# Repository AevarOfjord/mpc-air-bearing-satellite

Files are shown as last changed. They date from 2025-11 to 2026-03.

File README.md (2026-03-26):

# Satellite Thruster Control System





> **📌 Read-Only Reference Implementation**
>
> This repository is provided as a **complete reference implementation** for educational and research use. It is **not actively maintained** for external contributions.
>
> - ✅ **Download, fork, and modify** for your own research
> - ✅ **Open a GitHub issue** for bugs, documentation problems, or questions about the reference implementation
> - ❌ **Pull requests are not accepted** for this repository
> - ❌ **GitHub Discussions are not enabled**
> - 📧 **For urgent matters**: ofjord99@gmail.com

---

## What is This?

An **autonomous satellite control system** that uses **Model Predictive Control (MPC)** to navigate a satellite testbed on a 6×6 meter air-bearing table.

**In plain terms**: A small satellite floats frictionlessly on air bearings. It uses 8 compressed air thrusters and advanced control algorithms to move to targets and follow paths. Everything runs in software (simulation) or on real hardware.

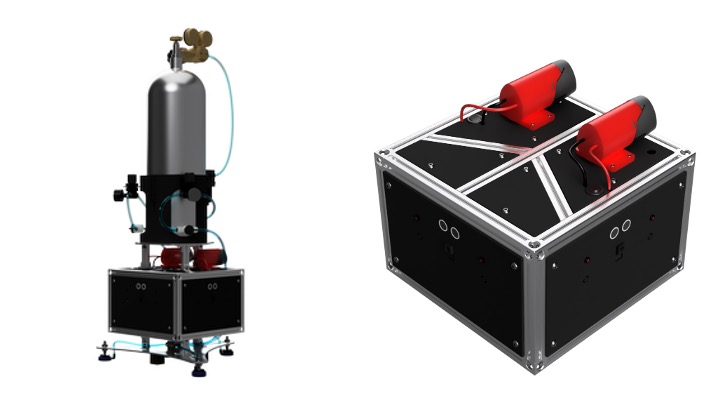
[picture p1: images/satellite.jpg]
Rendered Images of the Satellite and the Platform


---

## Quick Start

### 1. Install Python Dependencies
```bash
python3 -m pip install .
```

### 2. Get Gurobi License (Free for Academia)
- Visit: https://www.gurobi.com/academia/academic-program-and-licenses/
- Register with `.edu` email → download `gurobi.lic`
- Keep `gurobi.lic` local only. Placing it in the project root is supported and gitignored.

### 3. Run Simulation
```bash
satellite-sim
```
Follow the prompts to navigate to waypoints or follow shapes.

---

## What's Included

| What | What it Does | Command |
|---|---|---|
| **simulation.py** | Run MPC control on virtual satellite | `satellite-sim` or `python3 simulation.py` |
| **real.py** | Run MPC control on real hardware | `satellite-real` or `python3 real.py` |
| **mpc.py** | MPC solver & optimization logic | Imported by sim/real |
| **visualize.py** | Creates animations & performance plots (done automatically after each run, or manually) | `satellite-visualize` or `python3 visualize.py` |
| **comparison.py** | Compare sim vs real hardware results | `python3 comparison.py` |
| **testing_environment.py** | Manual control interface | `satellite-test` or `python3 testing_environment.py` |
| **config/** | All system parameters (physics, timing, MPC) | Import as needed |

---

## Documentation

### I'm taking over this project (handoff)
→ See [HANDOFF_GUIDE.md](HANDOFF_GUIDE.md) - Week 1 checklist, system health checks, maintenance schedule, known quirks

### I want to understand the system architecture
→ See [ARCHITECTURE.md](ARCHITECTURE.md) - Deep dive into control algorithms, physics model, module design

### I want to run hardware tests
→ See [HARDWARE_TEST_PROCEDURE.md](HARDWARE_TEST_PROCEDURE.md) - Safety checks, calibration, real-world testing

### I want to understand the mission types
→ See [MISSION_ARCHITECTURE.md](MISSION_ARCHITECTURE.md) - Waypoint navigation, shape following, DXF support

### I want to extend or modify the code
→ See [DEVELOPMENT_GUIDE.md](DEVELOPMENT_GUIDE.md) - Adding features, code style, testing your changes

### I want comprehensive simulation testing
→ See [SIMULATION_TESTING_GUIDE.md](SIMULATION_TESTING_GUIDE.md) - Simulation modes, parameter tuning, validation

### I want to understand data formats
→ See [CSV_FORMAT.md](CSV_FORMAT.md) - Data structure, analysis examples

### I want to write or understand tests
→ See [TESTING_GUIDE.md](TESTING_GUIDE.md) - Test structure, running tests, writing new tests

### I encountered a problem
→ See [TROUBLESHOOTING.md](TROUBLESHOOTING.md) - Installation, runtime, hardware, and data issues

---

## Key Features

- **Full Simulation**: Physics-based satellite dynamics with realistic thruster behavior
- **Real Hardware Control**: MPC on actual 6×6m air-bearing testbed
- **8 Thruster Control**: Individual calibration for each thruster
- **Multiple Mission Types**: Waypoint navigation, shape following (circle, rectangle, triangle, hexagon, custom DXF)
- **Visualization**: Animated results + performance plots
- **Comprehensive Tests**: 300+ unit and integration tests
- **Research Foundation**: Modular, extensible architecture for new control strategies

---

## Installation

### Prerequisites
- **Python 3.9, 3.10, 3.11, or 3.12** (3.13+ not supported yet)
- Check your version: `python3 --version`

### Steps
```bash
# 1. Install the package and runtime dependencies
python3 -m pip install .

# 2. Get free academic Gurobi license
# - Visit: https://www.gurobi.com/academia/academic-program-and-licenses/
# - Register with .edu email → download gurobi.lic
# - Keep gurobi.lic local only
# - Project root is supported and gitignored

# 3. Install FFmpeg
# macOS: brew install ffmpeg
# Linux: sudo apt install ffmpeg
# Windows: https://ffmpeg.org/download.html

# 4. Verify everything works
python3 -c "import gurobipy; print('Gurobi OK')"
python3 simulation.py
```

---

## Common Tasks

| Task | Command | Output |
|---|---|---|
| Run simulation | `python3 simulation.py` | CSV data + MP4 animation + plots |
| Run hardware control | `python3 real.py` | Live hardware control + CSV data + MP4 animation + plots + Live video |
| Generate visualizations | `python3 visualize.py` | Manually creates MP4 animation + PNG plots from selected CSV data file|
| Compare sim vs real | `python3 comparison.py` | Side-by-side analysis |
| Manual control in simulated environment| `python3 testing_environment.py` | Live interactive interface to test simulation environment |
| Run tests | `pytest` | Test results + coverage |

---

## Troubleshooting

**Python 3.13+ not supported?**
→ Use Python 3.9-3.12 instead. Install from https://www.python.org/downloads/

**"No module named gurobipy"?**
→ Install Gurobi (free academic license) and keep `gurobi.lic` local only. The project root is supported and gitignored.

**Serial port errors?**
→ Update `SERIAL_PORT` in config/constants.py. Check Device Manager (Windows) or `ls /dev/tty.*` (Mac/Linux)

**MPC solver too slow?**
→ Reduce `MPC_PREDICTION_HORIZON` in config/mpc_params.py

**FFmpeg not found?**
→ Install FFmpeg or update `FFMPEG_PATH` in config

For more troubleshooting, see [TROUBLESHOOTING.md](TROUBLESHOOTING.md)

---

## About This Project

Master's thesis project from University of Kentucky Mechanical Engineering. The system demonstrates Model Predictive Control for autonomous satellite navigation on a 6×6m air-bearing testbed.

**Why it exists**: Research platform for studying MPC-based attitude and position control with real hardware validation.

**Who should use it**: Researchers, students, and educators interested in control systems and autonomous satellite operations.

### Vision for Others

This project was designed with **extensibility and replicability** in mind. If you're interested in MPC research or small satellite testing:

- **Download and adapt**: Fork this repo and customize for your hardware
- **Reference implementation**: Use as a starting point so you don't have to build from scratch
- **MPC controller**: The core `mpc.py` works with any air-bearing testbed (adjust physics parameters)
- **Simulation**: Validate algorithms in software before hardware investment

**Note**: I want to maintain this as a reference implementation. You're welcome to fork and adapt it for your own research, but modifications stay on your own copy. This ensures the canonical version remains stable for others.

---

## Contributing

This is a personal research project released for educational and reference use. I do **not accept pull requests**, but you can fork and modify it for your own work.

### If you find issues:

- **Report bugs or documentation issues**: Open an issue at https://github.com/AevarOfjord/mpc-air-bearing-satellite/issues
- **Hardware concerns**: Use the same issue tracker and include setup details, logs, and reproduction steps
- **Questions about adapting the project**: Open an issue so the answer is visible to future users of the reference repo

### Want to modify the code?

**Fork and adapt for your research.** See [DEVELOPMENT_GUIDE.md](DEVELOPMENT_GUIDE.md) for setup and workflow details.

**Note**: This project is released as-is for educational and reference use. Bug fixes and improvements are made on a best-effort basis through the maintainer's own branch, not through incoming pull requests.

---

## Credits and Acknowledgments

**Author**: Aevar Amundinusarson Oefjoerd (Master's Thesis Project)

**Advisors**:
- Dr. Poonawala
- Dr. Seigler

**Institution**: University of Kentucky, Department of Mechanical Engineering

**Key Technologies**:
- **Gurobi Optimization**: Academic license for MPC solver
- **Python Scientific Stack**: NumPy, SciPy, Matplotlib
- **PyQt5**: User interface framework
- **OptiTrack Motive**: Motion capture system
- **FFmpeg**: Video generation

**Acknowledgments**:
- Dr. Poonawala, Dr. Seigler, UK Mechanical Engineering faculty and staff for facility access and support
- Open source community for excellent tools and libraries

---

## Support

**Repository**: https://github.com/AevarOfjord/mpc-air-bearing-satellite

**Issues**: https://github.com/AevarOfjord/mpc-air-bearing-satellite/issues

Need help? Check [TROUBLESHOOTING.md](TROUBLESHOOTING.md) or open an issue.

---

**Ready to get started?**
```bash
satellite-sim
```

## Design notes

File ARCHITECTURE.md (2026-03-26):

# Satellite Thruster Control System - Architecture Documentation

This document provides a complete file listing and description of the system architecture. For project overview and features, see [README.md](README.md).

---

## Directory Structure
```
mpc-air-bearing-satellite/
│
├── Main Entry Points (root level)
│   ├── simulation.py                 # Simulation environment launcher
│   ├── real.py                       # Real hardware control launcher
│   ├── visualize.py                  # Unified visualization & animation
│   ├── comparison.py                 # Compare simulation vs real results
│   └── testing_environment.py        # Interactive physics testing
│
├── Core Control & Physics
│   ├── mpc.py                        # Model Predictive Control optimizer
│   ├── model.py                      # Satellite physics model
│   ├── mission.py                    # Mission logic & waypoint handling
│   ├── mission_state_manager.py      # Track mission state
│   └── mission_report_generator.py   # Generate mission reports
│
├── Hardware & Communication
│   ├── satellite_hardware_interface.py   # Serial communication
│   ├── telemetry_client.py              # Motion capture data polling
│   └── camera_manager.py                # Multi-camera streaming
│
├── Navigation & Planning
│   ├── path_planning_manager.py     # Obstacle avoidance
│   └── navigation_utils.py          # Geometric utilities
│
├── Data & Logging
│   ├── data_logger.py               # CSV export
│   ├── extract_initial_velocities.py # Velocity extraction
│   └── real_data_simulated.py       # Data playback
│
├── UI & Visualization
│   ├── simulation_visualization.py   # Animation generation
│   ├── real_ui_components.py        # Real-time dashboard
│   ├── gui_components.py            # Shared GUI components
│   └── visualization_manager.py     # Visualization orchestration
│
├── Modes & Setup
│   ├── simulation_test_modes.py      # Simulation mode menu
│   ├── real_test_modes.py           # Hardware mode menu
│   ├── mode_setup_manager.py        # Unified setup logic
│   └── simulation_state_validator.py # State validation
│
├── Utilities & Infrastructure
│   ├── exceptions.py                # Custom exceptions
│   ├── logging_config.py            # Logging configuration
│   └── satellite_config.py          # Central config wrapper interface
│
├── Configuration System (config/)
│   ├── __init__.py                  # Package initialization
│   ├── physics.py                   # Physical parameters
│   ├── timing.py                    # Timing parameters
│   ├── mpc_params.py                # MPC tuning parameters
│   ├── camera.py                    # Camera configuration
│   ├── constants.py                 # System constants
│   ├── mission_state.py             # Mission state
│   └── obstacles.py                 # Obstacle definitions
│
├── Motion Capture Integration (Motive/)
│   ├── nat_net_client.py            # NatNet protocol client
│   ├── motive_data_server.py        # HTTP data server
│   ├── mocap_data.py                # Motion capture data structures
│   └── data_descriptions.py         # NatNet format definitions
│
├── Shape & DXF Processing (DXF/)
│   ├── __init__.py                  # Package initialization
│   ├── dxf_viewer.py                # DXF file viewer
│   ├── dxf_shape_maker.py           # DXF file creator
│   └── DXF_Files/                   # Pre-defined shape files
│       ├── Shape1.dxf
│       ├── Shape2.dxf
│       ├── Shape3.dxf
│       ├── Shape4.dxf
│       └── Shape5.dxf
│
├── Thruster Testing & Calibration (Thruster_Test/)
│   ├── thruster_test.py             # Sequential thruster verification
│   ├── thrust_calibration.py        # Thruster force calibration
│   ├── analyze_thruster_data.py     # Calibration data analysis
│   └── Thruster_Data/               # Calibration test results
│
├── Testing Infrastructure (tests/)
│   ├── __init__.py                  # Package initialization
│   ├── README.md                    # Testing documentation
│   ├── conftest.py                  # pytest configuration
│   ├── test_config.py               # Configuration tests
│   ├── test_mpc_controller.py       # MPC tests
│   ├── test_model.py                # Physics model tests
│   ├── test_mission_state_manager.py # Mission state tests
│   ├── test_path_planning_manager.py # Path planning tests
│   ├── test_navigation_utils.py     # Navigation utility tests
│   ├── test_data_logger.py          # Data logging tests
│   ├── test_camera_manager.py       # Camera manager tests
│   ├── test_simulation_state_validator.py # State validation tests
│   ├── test_integration_basic.py    # Basic integration tests
│   └── test_integration_missions.py # Mission integration tests
│
├── Data Output (Data/)
│   ├── Simulation/                  # Simulation results
│   ├── Real_Test/                   # Hardware test results
│   └── Comparison/                  # Comparative analysis
│
├── Project Files
│   ├── README.md                    # Project overview & quick start
│   ├── ARCHITECTURE.md              # This file
│   ├── MISSION_ARCHITECTURE.md      # Mission system architecture
│   ├── HANDOFF_GUIDE.md             # Handoff documentation
│   ├── QUICK_START_CHECKLIST.md     # First week checklist
│   ├── HARDWARE_TEST_PROCEDURE.md   # Hardware testing guide
│   ├── THRUSTER_CALIBRATION.md      # Thruster calibration guide
│   ├── DEVELOPMENT_GUIDE.md         # Development guidelines
│   ├── TESTING_GUIDE.md             # Testing documentation
│   ├── SIMULATION_TESTING_GUIDE.md  # Simulation testing guide
│   ├── TROUBLESHOOTING.md           # Troubleshooting guide
│   ├── CSV_FORMAT.md                # CSV data format documentation
│   ├── CODE_OF_CONDUCT.md           # Code of conduct
│   ├── SECURITY.md                  # Security policy
│   ├── LESSONS_LEARNED.md           # Development lessons learned
│   ├── requirements.txt             # Python dependencies
│   ├── pyproject.toml               # Project metadata
│   ├── .gitignore                   # Git ignore rules for local artifacts and secrets
│   └── LICENSE                      # License
│
├── Images (images/)                 # Project images and diagrams
│
└── Virtual Environment (venv/)      # Python virtual environment

```

---

## Complete File Listing

### Root Level - Main Entry Points

| File | Purpose |
|---|---|
| [simulation.py](simulation.py) | Main entry point for physics-based simulation of satellite control with MPC optimization. |
| [real.py](real.py) | Main entry point for real hardware control system that interfaces with microcontroller and motion capture. |
| [visualize.py](visualize.py) | Unified visualization system that generates MP4 animations and performance plots from CSV data. |
| [comparison.py](comparison.py) | Compares simulation results against real hardware test results side-by-side. |
| [testing_environment.py](testing_environment.py) | Interactive testing interface for virtual satellite simulation and physics validation. |

### Core Control & Physics

| File | Purpose |
|---|---|
| [mpc.py](mpc.py) | Model Predictive Control optimizer using Gurobi to generate thruster commands. |
| [model.py](model.py) | Static 2D visualization of the satellite layout (thruster positions, COM, air bearings). |
| [mission.py](mission.py) | Unified mission module supporting waypoint navigation and shape-following behaviors. |
| [mission_state_manager.py](mission_state_manager.py) | Tracks mission state, waypoint progress, and determines when targets are reached. |
| [mission_report_generator.py](mission_report_generator.py) | Generates text summaries and performance analysis after missions complete. |

### Hardware & Communication

| File | Purpose |
|---|---|
| [satellite_hardware_interface.py](satellite_hardware_interface.py) | Abstracts serial communication with microcontroller for thruster commands. |
| [telemetry_client.py](telemetry_client.py) | HTTP client that polls motion capture data from Motive data server. |
| [camera_manager.py](camera_manager.py) | Manages multi-camera streaming and recording from ESP32-CAM modules. |

### Navigation & Planning

| File | Purpose |
|---|---|
| [path_planning_manager.py](path_planning_manager.py) | Generates safe paths around obstacles using intermediate waypoint insertion. |
| [navigation_utils.py](navigation_utils.py) | Geometric utilities for distance calculations, angle conversions, and path validation. |

### Data & Logging

| File | Purpose |
|---|---|
| [data_logger.py](data_logger.py) | Exports mission state and control data to CSV format for analysis. |
| [extract_initial_velocities.py](extract_initial_velocities.py) | Utility to extract initial velocity estimates from CSV data for controller initialization. |
| [real_data_simulated.py](real_data_simulated.py) | Playback mode that replays real hardware data through simulation.|

### UI & Visualization

| File | Purpose |
|---|---|
| [simulation_visualization.py](simulation_visualization.py) | Generates real-time animation of satellite trajectory with thrust vectors during simulation. |
| [real_ui_components.py](real_ui_components.py) | PyQt5 components for real-time monitoring dashboard during hardware missions. |
| [gui_components.py](gui_components.py) | Shared GUI components and widgets used across both simulation and hardware modes. |
| [visualization_manager.py](visualization_manager.py) | Orchestrates animation generation, plot creation, and media export. |

### Configuration System

| File | Purpose |
|---|---|
| [config/__init__.py](config/__init__.py) | Configuration package exports all dataclass modules. |
| [config/physics.py](config/physics.py) | Physical parameters: satellite mass, inertia, thruster positions, forces, drag coefficients. |
| [config/timing.py](config/timing.py) | Timing parameters: simulation timestep, control rate, stabilization delays. |
| [config/mpc_params.py](config/mpc_params.py) | MPC tuning: prediction horizon, control horizon, cost weights, constraints. |
| [config/camera.py](config/camera.py) | Camera configuration: ESP32-CAM URLs, recording settings, frame rates. |
| [config/constants.py](config/constants.py) | System constants: serial ports, network parameters, data paths, UI dimensions. |
| [config/mission_state.py](config/mission_state.py) | Runtime mission state tracking: waypoints, targets, phase information. |
| [config/obstacles.py](config/obstacles.py) | Obstacle definitions: circular obstacles with safety radii for path planning. |

### Modes & Setup

| File | Purpose |
|---|---|
| [simulation_test_modes.py](simulation_test_modes.py) | Interactive menu for selecting simulation scenarios (waypoint, shapes, DXF). |
| [real_test_modes.py](real_test_modes.py) | Interactive menu for real hardware missions with manual parameter input. |
| [mode_setup_manager.py](mode_setup_manager.py) | Unified setup logic for initializing simulation or hardware modes. |
| [simulation_state_validator.py](simulation_state_validator.py) | Validation checks for simulation state consistency and physics constraints. |

### Utilities & Infrastructure

| File | Purpose |
|---|---|
| [exceptions.py](exceptions.py) | Custom exception classes for mission, hardware, and control errors. |
| [logging_config.py](logging_config.py) | Centralized logging configuration with file and console handlers. |
| [satellite_config.py](satellite_config.py) | Unified wrapper interface for accessing configuration modules with thruster calibration support. |

### Motion Capture Integration (Motive)

| File | Purpose |
|---|---|
| [Motive/nat_net_client.py](Motive/nat_net_client.py) | OptiTrack NatNet protocol client for receiving UDP motion capture packets. |
| [Motive/motive_data_server.py](Motive/motive_data_server.py) | HTTP server exposing latest motion capture data as JSON endpoints. |
| [Motive/mocap_data.py](Motive/mocap_data.py) | Data structures for rigid body tracking, skeletons, markers, and force plates. |
| [Motive/data_descriptions.py](Motive/data_descriptions.py) | NatNet packet format definitions and unpacking utilities. |

### Shape & DXF Processing

| File | Purpose |
|---|---|
| [DXF/dxf_viewer.py](DXF/dxf_viewer.py) | Loads and visualizes DXF shape files with customizable offset and smoothing. |
| [DXF/dxf_shape_maker.py](DXF/dxf_shape_maker.py) | Creates DXF shape files for defining custom mission paths and obstacles. |
| [DXF/__init__.py](DXF/__init__.py) | DXF module package initialization. |

### Thruster Testing & Calibration

| File | Purpose |
|---|---|
| [Thruster_Test/thruster_test.py](Thruster_Test/thruster_test.py) | Quick sequential verification that fires each of 8 thrusters for 1 second. |
| [Thruster_Test/thrust_calibration.py](Thruster_Test/thrust_calibration.py) | Measures actual thruster forces and updates physics configuration with calibrated values. |
| [Thruster_Test/analyze_thruster_data.py](Thruster_Test/analyze_thruster_data.py) | Analyzes thrust calibration data and generates performance statistics. |

### Testing Infrastructure

| File | Purpose |
|---|---|
| [tests/__init__.py](tests/__init__.py) | Test package initialization. |
| [tests/README.md](tests/README.md) | Testing documentation and guidelines. |
| [tests/conftest.py](tests/conftest.py) | pytest fixtures and configuration for unit and integration tests. |
| [tests/test_config.py](tests/test_config.py) | Tests for configuration system and parameter validation. |
| [tests/test_mpc_controller.py](tests/test_mpc_controller.py) | Tests for MPC optimization, constraint handling, and solver accuracy. |
| [tests/test_model.py](tests/test_model.py) | Tests for physics model linearization and state updates. |
| [tests/test_mission_state_manager.py](tests/test_mission_state_manager.py) | Tests for mission state tracking and waypoint detection. |
| [tests/test_path_planning_manager.py](tests/test_path_planning_manager.py) | Tests for obstacle avoidance and path validation. |
| [tests/test_navigation_utils.py](tests/test_navigation_utils.py) | Tests for geometric calculations and angle conversions. |
| [tests/test_data_logger.py](tests/test_data_logger.py) | Tests for CSV export and data format correctness. |
| [tests/test_camera_manager.py](tests/test_camera_manager.py) | Tests for camera streaming and recording functionality. |
| [tests/test_simulation_state_validator.py](tests/test_simulation_state_validator.py) | Tests for physics constraint validation. |
| [tests/test_integration_basic.py](tests/test_integration_basic.py) | Integration tests for basic mission execution. |
| [tests/test_integration_missions.py](tests/test_integration_missions.py) | Integration tests for complex multi-waypoint and shape-following missions. |

---

## Architecture Layers

The system is organized into logical layers:

1. **User/Test Input** – mission scripts (`mission.py`, the test-mode menus) collect targets, mission type, obstacles, etc.
2. **Entry Point** – either `simulation.py` or `real.py` boots up the runtime, wiring in mission config, MPC, logging, visualization, etc.
3. **Mission Logic** – `mission_state_manager.py` (plus `path_planning_manager.py` if obstacles exist) figures out the current waypoint/DXF segment the controller needs to track.
4. **MPC Optimization** – `mpc.py` linearizes around the current state, builds the MIQP, and solves for the next thruster sequence.
5. **Execution Layer** – the optimal command is applied either to the virtual satellite (`SatelliteThrusterTester` in the simulator) or over to the real hardware via `satellite_hardware_interface.py` + OptiTrack telemetry.
6. **Data & Visualization** – every step is logged (`data_logger.py`) and rendered (`visualize.py`) after the mission has completed/stopped.

```mermaid
graph TD
    U[User / Mission Input<br/><code>mission.py</code>, test modes] --> A[Workflow Entry<br/><code>simulation.py</code> or <code>real.py</code>]
    A --> B[Mission Logic<br/><code>mission_state_manager.py</code><br/>Path planning if needed]
    B --> C[MPC Optimization<br/><code>mpc.py</code><br/>Build/solve MIQP]
    C --> D[Execution Layer<br/>Simulation: <code>SatelliteThrusterTester</code><br/>Hardware: <code>satellite_hardware_interface.py</code> + OptiTrack]
    D --> E[Data & Visualization<br/><code>data_logger.py</code> · <code>visualize.py</code> · dashboards]
    G[[Configuration Layer<br/><code>config/*</code> dataclasses]] -. feeds all .-> U
    G -. feeds all .-> A
    G -. feeds all .-> B
    G -. feeds all .-> C
    G -. feeds all .-> D
    G -. feeds all .-> E

    style U fill:#fff5d9,stroke:#d97706,stroke-width:1.2px
    style A fill:#dbeafe,stroke:#1d4ed8,stroke-width:1.2px
    style B fill:#dcfce7,stroke:#15803d,stroke-width:1.2px
    style C fill:#fce7f3,stroke:#be185d,stroke-width:1.2px
    style D fill:#fef9c3,stroke:#ca8a04,stroke-width:1.2px
    style E fill:#ede9fe,stroke:#6d28d9,stroke-width:1.2px
    style G fill:#f5f5f5,stroke:#374151,stroke-width:1.2px,stroke-dasharray: 5 3
```

---

### **Key Architectural Differences**

| Aspect | Simulation Mode | Hardware Mode |
|---|---|---|
| **State Source** | Ground truth from `SatelliteThrusterTester` | OptiTrack telemetry via `telemetry_client.py` |
| **Satellite Dynamics** | 50 Hz integrator with valve delays, ramp-up/down, damping, and optional disturbances (`testing_environment.py`) | Physical air-bearing vehicle with solenoids and supply pressure dynamics |
| **Sensor Input** | Perfect pose plus OptiTrack-like noise injected by `SimulationStateValidator` when `USE_REALISTIC_PHYSICS=True` | Raw OptiTrack pose differentiated in `real.py:update_state_from_telemetry()` |
| **Thruster Execution** | Commands immediately update the simulated valves; the same delay/ramp profiles are emulated in software | Commands are serialized through `satellite_hardware_interface.py` to the microcontroller and actuate the real valves |
| **Telemetry Path** | Internal state arrays (no networking) | HTTP polling from `Motive/motive_data_server.py` with retry/backoff |
| **Control Output** | Applied directly to the physics loop | Sent to the hardware interface (serial/UDP/TCP) |

Both modes call `MissionStateManager.update_target_state()` immediately before every MPC solve; the only difference is whether the current state comes from OptiTrack or the simulator and whether the vehicle response is physical hardware or the `SatelliteThrusterTester`.

---

### **Common Elements**

Both simulation and hardware modes use the same components for core functionality:

1. **MPC Controller** (`mpc.py`) - Identical optimization engine for both
2. **Mission Logic** (`mission.py`) - Same waypoint/shape-following logic
3. **Data Logging** (`data_logger.py`) - Identical CSV recording format
4. **Path Planning** (`path_planning_manager.py`) - Shared
5. **Post-Processing** (`visualize.py`) - Same animation/plot generation

---

## Key Design Principles

- **Modularity:** Each file has a single, clear responsibility
- **Configuration-driven:** All parameters in `config/` dataclasses
- **Simulation/Hardware parity:** Same `mpc.py` and `mission.py` code used for both modes
- **Testing:** Comprehensive unit and integration tests for all core components
- **Documentation:** Each file has docstring describing its purpose

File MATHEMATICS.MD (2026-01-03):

# Mathematical Documentation

## Notation Conventions

| Notation | Meaning | Example |
| --- | --- | --- |
| **Bold lowercase** (𝐱, 𝐮, 𝐯) | Column vectors | 𝐱 = [x, y, θ]ᵀ |
| **Bold uppercase** (𝐀, 𝐁, 𝐑) | Matrices | 𝐀 ∈ ℝ⁶ˣ⁶ |
| Subscript k | Time step index | x_k (state at time k) |
| Superscript \* | Optimal value | u\* (optimal control) |
| Hat (x̂) | Estimated/predicted value | x̂\_{k+1} (predicted state) |
| Δ (delta prefix) | Deviation from nominal / discrete step | Δx = x - x₀, Δt = timestep |
| ‖·‖ | Euclidean norm | ‖𝐱‖ = √(x² + y²) |
| ‖·‖\_Q | Weighted norm | ‖𝐱‖²_Q = 𝐱ᵀQ𝐱 |
| ∈ | Element of set | u ∈ {0,1} |
| ℝ | Real numbers | x ∈ ℝ |
| 𝒪(·) | Big-O notation: "scales as" or "on the order of" | Error = 𝒪(Δt²) means error grows proportionally to Δt² |

**Frame Notation:**

- Subscript "world" or "w": world/inertial frame tied to the OptiTrack reference
- Subscript "body" or "b": body-fixed frame that spins with the vehicle
- 𝐑(θ): rotation matrix from body to world frame, implemented in the dynamics linearization/integration code (`mpc.py`, `testing_environment.py`)

---

## Table of Contents

1. [Coordinate Systems & State Definition](#coordinate-systems--state-definition)
2. [3-DOF Rigid Body Dynamics](#3-dof-rigid-body-dynamics)
3. [Thruster Force Allocation](#thruster-force-allocation)
4. [Linearization for MPC](#linearization-for-mpc)
5. [Model Predictive Control Formulation](#model-predictive-control-formulation)
6. [Navigation Mathematics](#navigation-mathematics)
7. [Numerical Integration](#numerical-integration)
8. [Control Implementation Details](#control-implementation-details)
9. [Parameter Sensitivity & Tuning](#parameter-sensitivity--tuning)
10. [Solver Parameter Sensitivity](#solver-parameter-sensitivity)

---

## System Overview

### Hardware Architecture

The block diagram below is the control loop we run on hardware. OptiTrack feeds the state estimate, the MPC solves in the middle of each cycle, and the thruster interface pushes commands straight to the solenoid valves.

```mermaid
graph LR
    A[OptiTrack<br/>Motion Capture] -->|State<br/>Measurement| B[State<br/>Estimation]
    B -->|x_current| C[MPC<br/>Solver]
    D[Mission<br/>Planner] -->|x_target| C
    C -->|u*<br/>Thruster<br/>Commands| E[Satellite<br/>Hardware]
    E -->|Thruster<br/>Forces| F[Rigid Body<br/>Dynamics]
    F -->|x_new| A

    style C fill:#f9f,stroke:#333,stroke-width:3px
    style E fill:#bbf,stroke:#333,stroke-width:2px
    style A fill:#bfb,stroke:#333,stroke-width:2px
```

**Control Loop Frequency:** 16.67 Hz (60ms per cycle) – this matches the firmware assumptions and all timing constants in `config/timing.py`.

**Key Components:**

- **OptiTrack**: Provides satellite pose at 120 Hz with ~1 mm noise
- **MPC Solver**: Gurobi MIQP running every 60 ms on the host machine
- **Hardware Interface**: Handles the 8 binary thruster command
- **Dynamics**: Physical satellite obeying Newton’s laws with damping from external forces in the testing environment.

---

### Simulation Architecture

For development without the vehicle, we use a physics simulator that mimics the same signals seen by the controller:

```mermaid
graph LR
    A[Physics<br/>Simulator] -->|x_current<br/>Ground Truth| B[MPC<br/>Solver]
    C[Mission<br/>Planner] -->|x_target| B
    B -->|u*<br/>Thruster<br/>Commands| D[Dynamics<br/>Integration]
    D -->|Forces &<br/>Torques| E[Euler<br/>Integrator]
    E -->|x_new| A
    F[Disturbances<br/>& Noise] -.->|Optional<br/>Perturbations| D

    style B fill:#f9f,stroke:#333,stroke-width:3px
    style D fill:#ffa,stroke:#333,stroke-width:2px
    style A fill:#aff,stroke:#333,stroke-width:2px
    style F fill:#faa,stroke:#333,stroke-width:1px,stroke-dasharray: 5 5
```

**Simulation Loop Frequency:**

- **Control loop**: 16.67 Hz (60ms per cycle) - same as hardware
- **Physics integration**: 200 Hz (5ms per step) - Time step for how often the physics model is updated

**Key Differences from Hardware:**

- **Physics Simulator** replaces OptiTrack and can inject noise before the controller sees it.
- **Dynamics integration** takes the role of hardware interface by computing the exact forces/torques from the thruster commands.
- **Euler integrator** advances the equations of motion with Δt = 0.005 s (twelve physics steps per control cycle) for numerical stability.
- **Optional disturbances** adds external forces or noises to mimic hardware testing

**Important:** The controller always runs at 16.67 Hz. The 200 Hz loop is purely an internal physics timestep so the simulated vehicle behaves like the real one between solver updates.

---

### Architecture Comparison

| Component | Hardware System | Simulation System |
| --- | --- | --- |
| **State Measurement** | OptiTrack (120 Hz, ~1mm noise) | Perfect ground truth (noise can be added) |
| **Control Solver** | Same MPC (Gurobi) | Same MPC (Gurobi) |
| **Control Frequency** | 16.67 Hz (0.06s period) | 16.67 Hz (0.06s period) |
| **Actuation** | Solenoid valves (small delay in response) | Instantaneous (delay can be added) |
| **Dynamics** | Real physics + random disturbances | Euler integration + optional random disturbances |
| **Physics Update** | Continuous (real-time) | 200 Hz (dt = 0.005s discrete steps) |
| **Latency** | < 10ms | Instantaneous (delay can be added) |
| **Disturbances** | Unknown air currents, friction | Disturbance can be added |

---

### Simulation vs Real Implementation Quick Guide

| Aspect | Hardware path | Simulation path | Code anchors |
| --- | --- | --- | --- |
| **State source** | OptiTrack pose → `real.py` builds `[x, y, v_x, v_y, θ, ω]` every 60 ms | `SatelliteThrusterTester` propagates state and feeds `simulation.py` | `real.py:update_state_from_telemetry()`, `simulation.py:_initialize_from_active_config()`, `testing_environment.py:update_simulation()` |
| **Dynamics** | Actual satellite motion (air bearings, plumbing, disturbances) | Numerical integrator with optional drag, noise, and user-defined disturbances | `real.py` hardware loop, `testing_environment.py` (physics), `simulation.py:update_simulation_loop()` |
| **Thruster output**| `SatelliteHardwareInterface` serial packets + physical valve delays | Physics kernel mirrors valve delay + ramp-up/downs (can be disabled for idealized runs) | `satellite_hardware_interface.py`, `real.py:apply_thruster_command()`, `testing_environment.py:calculate_forces_and_torques()` |
| **Measurement noise** | OptiTrack noise (~1 mm, 0.05°) plus occasional dropouts | Ground truth with optional OptiTrack-like jitter injected before the MPC (enabled in “realistic” mode) | `real.py:update_state_from_telemetry()`, `testing_environment.py` noise block, `simulation.py` noise toggles |
| **Logging/reporting** | Data logger pulls from hardware loop, mission reports tagged as “real” runs | Exact same logging stack capturing simulation episodes | `data_logger.py`, `mission_report_generator.py`, `real.py:run_real_test()`, `simulation.py:run_simulation()` |
| **Mission logic**  | Shared `MissionStateManager` plus real-only safety interlocks | Shared `MissionStateManager` | `mission_state_manager.py`, `real.py:MissionStateManager(...)`, `simulation.py:MissionStateManager(...)` |

Use this table whenever you need to call out whether a derivation applies to the numerical simulator, the hardware loop, or both. Two practical switches to keep in mind:

- `SatelliteConfig.USE_REALISTIC_PHYSICS=True` (the default) makes the simulator honor the same valve delays, ramp profiles, damping, disturbances, and sensor noise that the hardware sees. Turning it off gives you an “instant thruster / noiseless telemetry” sandbox.
- OptiTrack delivers world-frame positions/angles directly, so the real loop never rotates thrust vectors, and the simulator must rotate every body-frame force through 𝐑(θ) each step before integrating.

---

## Symbol-to-Code Mapping

### Core Mathematical Concepts

| Symbol | Meaning | Code Variable(s) | File(s) | Notes |
| :----: | --- | --- | --- | --- |
| 𝐱 | State Vector [x, y, vₓ, vᵧ, θ, ω] | `x_current`, `state`, `current_state`, `self.state`, `state_history` | `mpc.py`, `simulation.py`, `real.py`, `testing_environment.py`, `mission_state_manager.py` | Note: MPC internally reorders to [x, y, θ, vₓ, vᵧ, ω] |
| 𝐮 | Control Vector (8 thrusters) | `u_vars`, `control_action`, `u`, `thruster_commands`, `prev_thrusters` | `mpc.py`, `simulation.py`, `real.py`, `satellite_hardware_interface.py`, `testing_environment.py` | Binary: u_i ∈ {0,1} |
| 𝐀 | State transition matrix (6×6) | `A` from `linearize_dynamics()` | `mpc.py` | Built/cached in `SatelliteMPCOptimized.linearize_dynamics()` every solve |
| 𝐁 | Control input matrix (6×8) | `B` from `linearize_dynamics()` | `mpc.py` | Angle-dependent, includes thruster geometry |
|  𝐑(θ)  | Rotation matrix (2×2) | Computed inline with `np.cos(theta)`, `np.sin(theta)` | `mpc.py`, `simulation.py`, `testing_environment.py` | Transforms body frame to world frame. **Not used in `real.py`** - OptiTrack provides state directly in world frame |

### Cost Function Weights

|  Symbol  | Meaning | Code Variable | File(s) | Default Value |
| :---: | --- | --- | --- | --- |
| Q | State cost matrix (6×6) | `self.Q`, `Q` | `mpc.py`, `config/mpc_params.py` | Diagonal: diag([Q_pos, Q_pos, Q_ang, Q_vel, Q_vel, Q_angvel]) |
|  Q_pos | Position weight (x, y) | `SatelliteConfig.Q_POSITION`, `mpc_params["Q_pos"]` | `config/mpc_params.py`, `mpc.py` | 1000 |
|  Q_vel | Velocity weight (vₓ, vᵧ) | `SatelliteConfig.Q_VELOCITY`, `mpc_params["Q_vel"]` | `config/mpc_params.py`, `mpc.py` | 1750 (adaptive) |
| Q_θ | Angle weight | `SatelliteConfig.Q_ANGLE`, `mpc_params["Q_ang"]` | `config/mpc_params.py`, `mpc.py` | 1000 |
| Q_ω | Angular velocity weight | `SatelliteConfig.Q_ANGULAR_VELOCITY`, `mpc_params["Q_angvel"]` | `config/mpc_params.py`, `mpc.py` | 1500 |
| R | Control effort weight (8×8) | `self.R`, `SatelliteConfig.R_THRUST`, `mpc_params["R_thrust"]` | `mpc.py`, `config/mpc_params.py` | 1.0 × I₈ (identity matrix) |
| R_switch | Switching penalty | `self.R_switch`, `SatelliteConfig.R_SWITCH`, `mpc_params["R_switch"]` | `mpc.py`, `config/mpc_params.py` | 0.0 (disabled by default) |

### Horizons and Timing

| Symbol | Meaning | Code Variable | File(s) | Value |
| :----: | --- | --- | --- | --- |
| N | Prediction horizon (steps) | `self.N`, `prediction_horizon`, `mpc_params["prediction_horizon"]` | `mpc.py`, `config/mpc_params.py` | 12 steps = 0.72s |
| M | Control horizon (steps) | `self.M`, `control_horizon`, `mpc_params["control_horizon"]` | `mpc.py`, `config/mpc_params.py` | 12 steps = 0.72s |
| Δt | Control timestep (seconds) | `self.dt`, `dt`, `CONTROL_DT`, `mpc_params["dt"]` | `mpc.py`, `config/mpc_params.py`, `config/timing.py`, `simulation.py`, `real.py` | 0.06s (16.67 Hz) |
| Δt_sim | Simulation timestep (seconds) | `dt`, `SIMULATION_DT` | `simulation.py`, `testing_environment.py`, `config/timing.py` | 0.005s (200 Hz physics integration) |

### Physical Parameters

| Symbol | Meaning | Code Variable | File(s) | Value |
| :----: | --- | --- | --- | --- |
| m | Satellite mass | `self.total_mass`, `satellite_params["mass"]`, `PhysicsConfig.total_mass`, `SatelliteConfig.TOTAL_MASS` | `mpc.py`, `simulation.py`, `testing_environment.py`, `config/physics.py`, `satellite_config.py` | 23.09 kg |
| I | Moment of inertia | `self.moment_of_inertia`, `satellite_params["inertia"]`, `PhysicsConfig.moment_of_inertia`, `SatelliteConfig.MOMENT_OF_INERTIA` | `mpc.py`, `simulation.py`, `testing_environment.py`, `config/physics.py`, `satellite_config.py` | 0.324 kg·m² |
|  c_d | Linear damping coefficient | `PhysicsConfig.linear_damping_coeff`, `SatelliteConfig.LINEAR_DAMPING_COEFF` | `simulation.py`, `testing_environment.py`, `config/physics.py`, `satellite_config.py` | 1.8 N·s/m |
|  c_r | Rotational damping coefficient | `PhysicsConfig.rotational_damping_coeff`, `SatelliteConfig.ROTATIONAL_DAMPING_COEFF`  | `simulation.py`, `testing_environment.py`, `config/physics.py`, `satellite_config.py` | 0.3 N·m·s/rad |
| L | Satellite size | `SatelliteConfig.SATELLITE_SIZE`, `satellite_params["size"]`, `PhysicsConfig.satellite_size` | `config/physics.py`, `satellite_config.py`, `simulation_visualization.py` | 0.29 m |

### Thruster Configuration

| Symbol | Meaning | Code Variable | File(s) | Notes |
| :---: | --- | --- | --- | --- |
| F_i | Thruster force magnitude (N) | `self.thruster_forces`, `THRUSTER_FORCES`, `satellite_params["thruster_forces"]` | `mpc.py`, `simulation.py`, `testing_environment.py`, `satellite_config.py`, `satellite_hardware_interface.py` | Array of 8 calibrated values (0.428-0.484 N) |
| 𝐫_i | Thruster position (body frame)  | `self.thruster_positions`, `THRUSTER_POSITIONS`, `satellite_params["thruster_positions"]` | `mpc.py`, `simulation.py`, `testing_environment.py`, `satellite_config.py` | (x, y) in meters, 8×2 array |
| 𝐝_i | Thruster direction (body frame) | `self.thruster_directions`, `THRUSTER_DIRECTIONS`, `satellite_params["thruster_directions"]` | `mpc.py`, `simulation.py`, `testing_environment.py`, `satellite_config.py` | Unit vectors, 8×2 array |
| τ_i | Thruster torque (N·m) | Computed inline: `r_x * F_y - r_y * F_x` | `mpc.py` (line ~280), `simulation.py`, `testing_environment.py` | τ = r × F (2D cross product) |
| n_thrusters | Number of thrusters | `8` (hardcoded), `len(thruster_forces)` | All files with thruster logic | Always 8 for this satellite |

### State Bounds and Constraints

| Symbol | Meaning | Code Variable | File(s) | Value |
| :---: | --- | --- | --- | --- |
| x_max, y_max | Position limits | `self.position_bounds`, `POSITION_BOUNDS`, `mpc_params["position_bounds"]` | `mpc.py`, `config/mpc_params.py`, `simulation_state_validator.py` | ±3.0 m (testbed boundary) |
| v_max | Velocity limit | `self.max_velocity`, `MAX_VELOCITY`, `mpc_params["max_velocity"]` | `mpc.py`, `config/mpc_params.py`, `simulation_state_validator.py` | 0.25 m/s (safety limit) |
| ω_max | Angular velocity limit | `self.max_angular_velocity`, `MAX_ANGULAR_VELOCITY`, `mpc_params["max_angular_velocity"]` | `mpc.py`, `config/mpc_params.py`, `simulation_state_validator.py` | π/2 rad/s ≈ 1.571 rad/s |
| θ_bounds | Angle bounds | ±2π bounds inside MPC, angles re-wrapped for telemetry/logs | `mpc.py` (state bounds), `navigation_utils.py` (normalization) | Solver clamps θ to ±2π; outputs normalized to [-π, π] |
| u_bounds | Control bounds | Binary constraint in Gurobi | `mpc.py` (line ~320) | u_i ∈ {0, 1} |

### Solver Parameters (Gurobi)

| Parameter  | Code Variable | File(s) | Value | Purpose |
| --- | --- | --- | --- | --- |
| MIPGap | `model.setParam('MIPGap', ...)` | `mpc.py` (line ~370) | 0.01 (1%) | Stop when within 1% of optimal |
| TimeLimit  | `model.setParam('TimeLimit', ...)`, `self.solver_time_limit` | `mpc.py` (line ~365), `config/mpc_params.py` | 0.05s (50ms) | Hard deadline for real-time control |
| MIPFocus | `model.setParam('MIPFocus', ...)` | `mpc.py` (line ~371) | 1 | Prioritize feasible solutions quickly |
| Threads | `model.setParam('Threads', ...)` | `mpc.py` (line ~373) | 1 | Single-threaded (avoids overhead) |
| Presolve | `model.setParam('Presolve', ...)` | `mpc.py` (line ~372) | 2 | Aggressive model simplification |
| Heuristics | `model.setParam('Heuristics', ...)` | `mpc.py` (line ~376) | 0.01 | Minimal time on heuristic searches |
| Cuts | `model.setParam('Cuts', ...)` | `mpc.py` (line ~377) | 1 | Moderate cutting plane generation |
| OutputFlag | `model.setParam('OutputFlag', ...)` | `mpc.py` (line ~374) | 0 | Suppress Gurobi console output |

### Navigation Utilities

| Function | Mathematical Operation | Code Function | File(s) | Used In |
| --- | --- | --- | --- | --- |
| Angle normalization  | θ → [-π, π] | `normalize_angle(angle)` | `navigation_utils.py` | `mpc.py`, `simulation.py`, `real.py`, `mission_state_manager.py` |
| Shortest rotation | min(θ₁→θ₂) | `angle_difference(target, current)` | `navigation_utils.py` | `mpc.py`, `mission.py`, `path_planning_manager.py` |
| Distance to line | d(P, AB) | `point_to_line_distance(point, line_start, line_end)` | `navigation_utils.py` | `path_planning_manager.py`, `mission.py` |
| Obstacle avoidance helper | Path planning with obstacles | `calculate_safe_path_to_waypoint()` | `navigation_utils.py` | `path_planning_manager.py`, `mission.py` |
| Distance calculation | ‖P₁ - P₂‖ | `np.linalg.norm(p1 - p2)` | Standard numpy | All files computing distances |
| Target reached check | Error < threshold | `MissionStateManager._handle_multi_point_mode()` | `mission_state_manager.py` | `mission.py`, `real.py`, `simulation.py` |

### Adaptive Behavior and Advanced Features

| Concept | Implementation | File(s) | Code Location | Parameters |
| --- | --- | --- | --- | --- |
| Velocity boost near target | Multiply Q_vel by up to 3× when close and still moving | `mpc.py` | `SatelliteMPCOptimized.get_control_action()` (~520-540)  | `DAMPING_ZONE = 0.25 m`, `VELOCITY_THRESHOLD = 0.03 m/s`, capped by `MAX_VELOCITY_WEIGHT = 1000` |
| Linearization caching | Quantize θ to 0.01 rad bins to reuse A, B matrices | `mpc.py` | `linearize_dynamics()` (~280-310) | Cache resolution: 0.01 rad ≈ 0.57° |
| Warm starting | Shift previous solution by 1 timestep | `mpc.py` | `_apply_warm_start()` (~520-560) | Copies `u[k+1]` → `u[k]`, provides `.Start` to Gurobi |
| Damping zone | Distance threshold for aggressive damping | `config/mpc_params.py` | `DAMPING_ZONE` | 0.25 m from target |
| Fallback controller | Simple proportional control if MPC fails | `mpc.py` | `_get_fallback_control()` (~700-750) | K_p gains tuned for stability |
| State validation | Check bounds before/after integration | `simulation_state_validator.py` | `validate_state()`, `enforce_constraints()` | Used in `simulation.py`, `testing_environment.py` |
| Mission state tracking | Track waypoints, timing, convergence | `mission_state_manager.py` | Full class | Used in `mission.py`, `real.py`, `simulation.py` |
| Data logging | Record all state, control, timing data | `data_logger.py` | Full class | Saves to CSV in `Data/` folder |

### Mission and Path Planning

| Concept | Code Variable/Class | File(s) | Description |
| --- | --- | --- | --- |
| Mission types | `"waypoint"`, `"shape"`, `"circling"` | `mission.py`, `simulation_test_modes.py`, `real_test_modes.py` | Different mission execution modes |
| Waypoint list | `waypoints` array of [x, y, θ] | `mission.py`, `mission_state_manager.py` | Target poses for waypoint missions |
| Current target | `x_target`, `target_state` | `mpc.py`, `simulation.py`, `real.py`, `mission.py` | Current goal passed to MPC |
| Path planner | `PathPlanningManager` class | `path_planning_manager.py` | Generates obstacle-free paths |
| Obstacles | `obstacles` list of circles (x, y, r) | `path_planning_manager.py`, `mission.py`, `config/obstacles.py` | Circular obstacles to avoid |
| Shape definitions | DXF file parsing | `DXF/dxf_shape_maker.py`, `mission.py` | Reads CAD shapes as waypoints |
| Mission manager | `MissionManager` class | `mission.py` | High-level mission orchestration |
| Mission state | `MissionStateManager` class | `mission_state_manager.py` | Tracks progress, timing, convergence |

### Hardware Interface (Real System Only)

| Component | Code Variable/Class | File(s) | Description |
| --- | --- | --- | --- |
| OptiTrack motion capture | `mocap_client`, `NatNetClient` | `real.py`, `Motive/nat_net_client.py`, `Motive/motive_data_server.py` | Gets satellite pose at 120 Hz in **world frame** (x, y, yaw) |
| Velocity estimation | `update_state_from_telemetry()` | `real.py` (lines ~440-465) | Finite differences: v = Δp/Δt, ω = Δθ/Δt (no rotation matrix needed) |
| Thruster hardware | `SatelliteHardwareInterface` | `satellite_hardware_interface.py` | Serial commands to Arduino/solenoids |
| Camera system | `SatelliteCameraWindow`, `CameraManager` | `camera_manager.py`, `real.py` | Multi-camera recording and streaming |
| Telemetry server | `TelemetryServer` | `telemetry_client.py` | WebSocket server for real-time data |
| UI components | PyQt5 windows and widgets | `real_ui_components.py`, `gui_components.py` | Live dashboard, controls, visualizations |
| Safety monitoring | Emergency stop, bound checking | `real.py` (main loop), `satellite_hardware_interface.py` | Prevents crashes and hardware damage |

**Key Difference from Simulation:**

- **Real system**: OptiTrack provides state already in world frame → no rotation matrix needed in `real.py`
- **Simulation**: Thruster forces start in body frame → rotation matrix required to transform to world frame before integration

### Visualization and Output

| Component | Code Variable/Class | File(s) | Description | Real System | Simulation  |
| --- | --- | --- | --- | --- | --- |
| Terminal output | `logger.info()` | `simulation.py` (~1100), `real.py` (~785) | Both systems print status to terminal: time, errors, thrusters | ✅ | ✅ |
| Real-time 2D plot  | `LiveAnimationWindow` | `real_ui_components.py`, `real.py` | Optional live matplotlib animation of satellite position | ✅ Optional | ❌ Not used |
| Camera streams | `SatelliteCameraWindow`, `CameraManager` | `camera_manager.py`, `real.py` | Live video from onboard cameras | ✅ Optional | ❌ N/A |
| Mission reports | `MissionReportGenerator` class | `mission_report_generator.py` | Post-mission analysis with plots | ✅ | ✅ |
| Unified visualizer | `UnifiedVisualizationGenerator` | `visualize.py` | Comprehensive post-mission plots and videos | ✅ | ✅ |
| Data comparison | `compare_missions()` | `comparison.py` | Compare multiple mission runs | ✅ | ✅ |

**Terminal Output Format (Both Systems):**

```
t= 12.3s: APPROACHING (t=12.3s) pos_err=0.452m, ang_err= 15.3°
 solve_time=0.003s, thrusters=[1, 5, 7]
```

### Data Logging and History

| Component | Code Variable/Class | File(s) | Description |
| --- | --- | --- | --- |
| State history | `state_history` list | `simulation.py`, `real.py` | Time series of all states |
| Control history | `control_history` list | `simulation.py`, `real.py` | Time series of thruster commands |
| Solve time tracking | `solve_times` list | `mpc.py`, `data_logger.py` | MPC performance metrics |
| Terminal messages | `log_terminal_message()` | `data_logger.py` | Logs all terminal output to CSV |
| CSV export | `save_to_csv()` | `data_logger.py` | Exports all logged data to `Data/` folder |

### Testing Infrastructure

| Component | File(s) | Description |
| --- | --- | --- |
| Unit tests | `tests/test_*.py` | pytest suite for individual components |
| Integration tests | `tests/test_integration_*.py` | End-to-end mission tests |
| Test environment  | `testing_environment.py` | Simplified simulator for fast testing  |
| Conftest fixtures | `tests/conftest.py` | Shared test fixtures and utilities |
| Test modes | `simulation_test_modes.py`, `real_test_modes.py` | Pre-configured test scenarios |

### Quick Code Lookup

**Core Algorithm:**

- **MPC optimization problem built**: `mpc.py`, `_build_persistent_model()` (~200-350)
- **Dynamics linearization**: `mpc.py`, `linearize_dynamics()` (~270-320)
- **MPC solve entry point**: `mpc.py`, `get_control_action()` (~420-500)
- **Dynamics integration**: `simulation.py`, `SatelliteMPCLinearizedSimulation.update_simulation()` (~1130-1400) and `testing_environment.py`, `SatelliteThrusterTester.update_simulation()` (~352-450)
- **Thruster forces computed**: `testing_environment.py`, `SatelliteThrusterTester.calculate_forces_and_torques()` (~262-330) – the simulator calls this helper each frame

**Control Loops:**

- **Hardware control loop**: `real.py`, `run_real_test()` (~1030-1125)
- **Simulation control loop**: `simulation.py`, `run_simulation()` (~1530-1660)
- **Test environment loop**: `testing_environment.py`, `run()` (~770-850)

**Configuration:**

- **MPC weights**: `config/mpc_params.py` (Q, R values)
- **Physical parameters**: `config/physics.py` (mass, inertia, damping)
- **Thruster calibration**: `satellite_config.py` (positions, directions, forces)
- **Constraints**: `config/mpc_params.py` (position/velocity/angular bounds)
- **Timing**: `config/timing.py` (dt, horizons)

**Utilities:**

- **Angle wrapping**: `navigation_utils.py`, `normalize_angle()` (~15-30)
- **Shortest angle path**: `navigation_utils.py`, `angle_difference()` (~35-50)
- **Distance calculations**: `navigation_utils.py`, `point_to_line_distance()` (~70-100)
- **State validation**: `simulation_state_validator.py`, `validate_state()` (~50-100)

**Data Management:**

- **Logging**: `data_logger.py`, entire file
- **Mission reports**: `mission_report_generator.py`, entire file
- **CSV export**: `data_logger.py`, `save_to_csv()` (~200-250)
- **Visualization generation**: `visualize.py`, entire file

---

## Coordinate Systems & State Definition

### State Vector

We track six states, all expressed in the world frame so they line up with OptiTrack measurements and log files:

$$\mathbf{x} = \begin{bmatrix} x \\ y \\ v_x \\ v_y \\ \theta \\ \omega \end{bmatrix}$$

Where:

- **x, y**: position in the world frame (meters)
- **vx, vy**: linear velocities in the world frame (m/s)
- **θ**: yaw angle in radians, and we allow it to wander outside [-π, π] inside the optimizer but wrap it for logs
- **ω**: yaw rate (rad/s)

**Implementation notes**

- **Real hardware:** `real.py` ingests OptiTrack poses, differentiates to get velocities (`update_state_from_telemetry()`), and hands the MPC `[x, y, v_x, v_y, θ, ω]` each 60 ms cycle.
- **Simulation:** `simulation.py` copies the truth state from `SatelliteThrusterTester` (already world-frame), so no extra rotation matrix is required—only the `[v_x, v_y, θ]` reorder inside `mpc.py`.

### Coordinate Frames

**World Frame (Inertial)**

- Fixed reference frame (X-Y plane) pinned to the OptiTrack.
- Positive X points right, positive Y points away from the cameras (up on the plots).
- Used for state estimates, logging, and the MPC formulation.

**Body Frame (Satellite)**

- Moves with the satellite, +X points “forward” along the body, and +Y points port-side.
- Thruster locations and directions are specified here because the mounts never move relative to the chassis.
- Any force defined in body coordinates must be rotated by 𝐑(θ) before applying Newton’s laws.

### Frame Transformation

The rotation matrix from body frame to world frame is:

$$\mathbf{R}(\theta) = \begin{bmatrix} \cos\theta & -\sin\theta \\ \sin\theta & \cos\theta \end{bmatrix}$$

To transform a force vector from body frame to world frame:

$$\mathbf{F}_{\text{world}} = \mathbf{R}(\theta) \cdot \mathbf{F}_{\text{body}}$$

Example: A thruster pointing in body-frame direction $\mathbf{d}_b = [-1, 0]^T$ with magnitude $F$ produces world-frame force:

$$\mathbf{F}_{\text{world}} = \begin{bmatrix} \cos\theta & -\sin\theta \\ \sin\theta & \cos\theta \end{bmatrix} \begin{bmatrix} -F \\ 0 \end{bmatrix} = \begin{bmatrix} -F\cos\theta \\ -F\sin\theta \end{bmatrix}$$

### Visualizing the Transformation

**The Big Picture:** How thruster commands become satellite motion

```mermaid
graph LR
    A["STEP 1<br/>Thruster Command<br/>ON/OFF for each thruster"] --> B["STEP 2<br/>Body Frame<br/>Position & Direction<br/>fixed on satellite"]
    B --> C["STEP 3<br/>Rotate by theta<br/>R theta matrix"]
    C --> D["STEP 4<br/>World Frame<br/>Forces & Torques<br/>fixed in space"]
    D --> E["STEP 5<br/>Sum All 8 Thrusters<br/>Total Force & Torque"]
    E --> F["STEP 6<br/>Newtons Laws<br/>F=ma, tau=I alpha"]
    F --> G["STEP 7<br/>New State<br/>Updated position<br/>velocity angle"]

    style A fill:#e3f2fd,stroke:#1976d2,stroke-width:2px
    style B fill:#fff3e0,stroke:#f57c00,stroke-width:2px
    style C fill:#fce4ec,stroke:#c2185b,stroke-width:2px
    style D fill:#e8f5e9,stroke:#388e3c,stroke-width:2px
    style E fill:#f3e5f5,stroke:#7b1fa2,stroke-width:2px
    style F fill:#fff9c4,stroke:#f9a825,stroke-width:2px
    style G fill:#e0f2f1,stroke:#00796b,stroke-width:2px
```

**Detailed View for One Thruster:**

```mermaid
graph TB
    subgraph Input["STEP 1: Input Body Frame"]
        A1["Thruster #1<br/>Position: 0.145, 0.06 m<br/>Direction: -1, 0<br/>Force: 0.441 N<br/>STATUS: ON"]
    end

    subgraph Rotate["STEP 2: Rotate to World Frame"]
        B1["Apply Rotation Matrix<br/>cos 45deg = 0.707<br/>sin 45deg = 0.707<br/>Satellite angle theta = 45deg"]
        B2["World Direction<br/>-0.707, -0.707<br/>now points SW"]
        B3["World Position<br/>≈0.060, 0.145 m<br/>rotated from body"]
    end

    subgraph Calculate["STEP 3: Calculate Effects"]
        C1["Force Vector<br/>F = 0.441 x -0.707, -0.707<br/>= -0.312, -0.312 N"]
        C2["Torque<br/>tau = position x force<br/>= 0.0265 N·m CCW"]
    end

    subgraph Repeat["STEP 4: Repeat for All 8 Thrusters"]
        D1["Thruster 1: F1, tau1<br/>Thruster 2: F2, tau2<br/>...<br/>Thruster 8: F8, tau8"]
    end

    subgraph Total["STEP 5: Sum Everything"]
        E1["Total Force<br/>F_total = F1 + F2 + ... + F8"]
        E2["Total Torque<br/>tau_total = tau1 + tau2 + ... + tau8"]
    end

    subgraph Apply["STEP 6: Apply to Satellite"]
        F1["Linear acceleration<br/>a = F_total / 23.09 kg"]
        F2["Angular acceleration<br/>alpha = tau_total / 0.324 kg·m2"]
        F3["Update velocity<br/>v_new = v + a × 0.005s"]
        F4["Update position<br/>x_new = x + v × 0.005s"]
        F5["Same for rotation"]
    end

    A1 --> B1
    B1 --> B2
    B1 --> B3
    B2 --> C1
    B3 --> C2
    C1 --> D1
    C2 --> D1
    D1 --> E1
    D1 --> E2
    E1 --> F1
    E2 --> F2
    F1 --> F3
    F2 --> F5
    F3 --> F4

    style Input fill:#e3f2fd,stroke:#1976d2,stroke-width:3px
    style Rotate fill:#fff3e0,stroke:#f57c00,stroke-width:3px
    style Calculate fill:#e8f5e9,stroke:#388e3c,stroke-width:3px
    style Repeat fill:#f3e5f5,stroke:#7b1fa2,stroke-width:3px
    style Total fill:#fff9c4,stroke:#f9a825,stroke-width:3px
    style Apply fill:#ffebee,stroke:#c62828,stroke-width:3px
```

**Why This Matters:**

- All of the physics (and the MPC) run in the world frame, so forces must be rotated before integration.

**Concrete Example:**

| Satellite Angle | Body Direction | World Direction | Effect |
| --- | --- | --- | --- |
| θ = 0° | [-1, 0] (left) | [-1, 0] (left)  | Pushes satellite left  |
| θ = 90° | [-1, 0] (left) | [0, -1] (down)  | Pushes satellite down  |
| θ = 180° | [-1, 0] (left) | [1, 0] (right)  | Pushes satellite right |
| θ = 270° | [-1, 0] (left) | [0, 1] (up) | Pushes satellite up |

**Code Implementation:** MPC linearization rotates forces in `mpc.py` (around lines 199–215), and the simulator mirrors the same operation when applying thrust in `testing_environment.py` (lines ~262–295).

---

## 3-DOF Rigid Body Dynamics

### Equation of Motion (Model Used for MPC Linearization)

The MPC linearizes a simplified planar rigid-body model. We keep only the thruster-generated accelerations and drop the damping/disturbance terms (those live exclusively in the high-fidelity simulator inside `testing_environment.py`). The linearization state is reordered to

$$\mathbf{x}_{\text{lin}} = [x,\, y,\, \theta,\, v_x,\, v_y,\, \omega]^T$$

even though the simulation state is `[x, y, v_x, v_y, θ, ω]`. Every solve therefore starts by shuffling the components into this MPC-specific order.

**Linear motion**

$$m \frac{d v_x}{dt} = F_x,\qquad m \frac{d v_y}{dt} = F_y$$

where $F_x$ and $F_y$ are the world-frame components of the summed thruster forces.

**Angular motion**

$$I \frac{d\omega}{dt} = \tau_{\text{thrust}}$$

with $\tau_{\text{thrust}} = \sum_i \mathbf{r}_i \times \mathbf{F}_i$ computed in the body frame before we rotate forces into world coordinates.

**Kinematics**

$$\frac{dx}{dt} = v_x,\qquad \frac{dy}{dt} = v_y,\qquad \frac{d\theta}{dt} = \omega$$

This minimal model is what `SatelliteMPCOptimized.linearize_dynamics()` discretizes each 60 ms control step.

**Implementation split**

- **Real hardware:** The physical satellite obviously follows the full nonlinear dynamics, so the MPC linearization is just a local approximation of what the air-bearing platform actually does.
- **Simulation:** `testing_environment.py` uses the richer model (damping, disturbances, valve delays) for propagation, but still feeds the simplified 6-state vector to the MPC so hardware and simulation share identical control math.

### Moment of Inertia Calculation

$$I = \frac{1}{6} m L^2 = \frac{1}{6} \times 23.09 \times 0.29^2 = 0.324 \, \mathrm{kg \cdot m^2}$$

---

## Thruster Force Allocation

### Thruster Configuration

Eight compressed-air thrusters are mounted symmetrically around the chassis. The table lists their body-frame positions, calibrated force magnitudes, and nominal directions.

| Thruster | Position (m) | Direction | Force (N) |
| --- | --- | --- | --- |
| 1 | (0.145, 0.06) | [-1, 0] (left) | 0.441 |
| 2 | (0.145, -0.06)  | [-1, 0] (left) | 0.431 |
| 3 | (0.06, -0.145)  | [0, 1] (up) | 0.428 |
| 4 | (-0.06, -0.145) | [0, 1] (up) | 0.438 |
| 5 | (-0.145, -0.06) | [1, 0] (right) | 0.469 |
| 6 | (-0.145, 0.06)  | [1, 0] (right) | 0.447 |
| 7 | (-0.06, 0.145)  | [0, -1] (down) | 0.467 |
| 8 | (0.06, 0.145) | [0, -1] (down) | 0.484 |

### Force Allocation from Control Commands

The MPC outputs binary control signals $u_i \in \{0, 1\}$ for each thruster. The force produced by thruster $i$ is:

$$\mathbf{F}_i = u_i \cdot F_{\text{mag},i} \cdot \mathbf{d}_{b,i}$$

Where:

- **u_i**: binary command (0 = valve closed, 1 = valve open).
- **F_mag,i**: measured thrust level from calibration.
- **d_b,i**: unit direction vector in body frame (pulled directly from `satellite_config.py`).

### Total Thruster Force in World Frame

First, compute the body-frame force sum:

$$\mathbf{F}_{b,\text{total}} = \sum_{i=1}^{8} u_i \cdot F_{\text{mag},i} \cdot \mathbf{d}_{b,i}$$

Then rotate to world frame:

$$\mathbf{F}_{\text{world}} = \mathbf{R}(\theta) \cdot \mathbf{F}_{b,\text{total}}$$

### Torque Generation

Torque is generated by off-center thrusters. For thruster $i$ at position $\mathbf{r}_i$ (body-relative) producing force $\mathbf{F}_{b,i}$:

$$\tau_i = r_{i,x} \cdot F_{b,i,y} - r_{i,y} \cdot F_{b,i,x}$$

This is the **cross product magnitude** in 2D: $\tau = \mathbf{r} \times \mathbf{F}$ (scalar in 2D).

Total torque:

$$\tau_{\text{total}} = \sum_{i=1}^{8} \tau_i$$

**Key detail**: Torque is independent of satellite orientation because both the lever arm and the force live in the body frame before rotation.

**Implementation notes**

- **Real hardware:** `SatelliteHardwareInterface` simply sends the binary fire command packet, and any valve-open delay is a physical effect of the solenoids that shows up naturally in telemetry/logs—`real.py` does not compensate or pre-shift commands.
- **Simulation:** `testing_environment.py` applies the same binary pattern inside the physics loop, and when `USE_REALISTIC_PHYSICS=True` (default) it emulates valve delays/ramp profiles so the simulator mirrors hardware behavior, and you can disable those effects via `SatelliteConfig` for idealized tests.

### Force and Torque Coupling Example

**Thruster pair 1 & 5** (horizontal opposing pair):

**Thruster 1:**

- Position: (0.145, 0.06) m
- Direction: [-1, 0] (pushing left)
- Force: F₁ = 0.441 N
- Force vector: **F₁** = 0.441[-1, 0] = [-0.441, 0] N
- Torque: τ₁ = x·Fᵧ - y·Fₓ = (0.145)(0) - (0.06)(-0.441) = **+0.0265 N·m** (CCW)

**Thruster 5:**

- Position: (-0.145, -0.06) m
- Direction: [1, 0] (pushing right)
- Force: F₅ = 0.469 N
- Force vector: **F₅** = 0.469[1, 0] = [0.469, 0] N
- Torque: τ₅ = x·Fᵧ - y·Fₓ = (-0.145)(0) - (-0.06)(0.469) = **+0.0281 N·m** (CCW)

**Net result when both fire:** Both create counterclockwise torque (0.0265 + 0.0281 = **+0.0546 N·m**) but minimal force since they almost cancel each other

- Net force: [-0.441, 0] + [0.469, 0] = [**+0.028, 0**] N ≈ 0
- Net torque: 0.0265 + 0.0281 = **+0.0546 N·m** ≠ 0

**Thruster pair 3 & 7** (vertical opposing pair):

**Thruster 3:**

- Position: (0.06, -0.145) m, Direction: [0, 1] (up)
- Force magnitude: 0.4277 N → force vector [0, 0.4277]
- Torque: τ₃ = x·Fᵧ - y·Fₓ = 0.06·0.4277 − (−0.145)·0 = **+0.0257 N·m** (CCW)

**Thruster 7:**

- Position: (-0.06, 0.145) m, Direction: [0, -1] (down)
- Force magnitude: 0.4670 N → force vector [0, −0.4670]
- Torque: τ₇ = (−0.06)(−0.4670) − 0.145·0 = **+0.0280 N·m** (CCW)

**Net result when both fire:** Both create counterclockwise torque (0.0257 + 0.0280 ≈ **0.0537 N·m**) but minimal force since they almost cancel each other

- Net force: [0, 0.4277] + [0, -0.4670] = [0, **-0.0393**] N ≈ 0
- Net torque: 0.0257 + 0.0280 ≈ **+0.0537 N·m** ≠ 0

**Takeaway:** Opposing thrusters (1&5, 3&7) cancel translational force but add torque because τ = **r** × **F** = x·Fᵧ - y·Fₓ.

---

## Linearization for MPC

### Why Linearization?

The only significant nonlinearity is the rotation-dependent force mapping (the 𝐑(θ) matrix). Every control cycle we grab the current state, call `linearize_dynamics()` to rebuild the A/B matrices around that operating point, and then hand those fresh matrices to Gurobi. Because the control loop runs at `CONTROL_DT = 0.06 s`, this rebuild happens once every 60 ms—i.e., 1 ÷ 0.06 = 16.67 times per second—so the linear model never drifts far from the true nonlinear dynamics and the MIQP stays small enough to solve in a few milliseconds.

### Continuous-Time Linearization

Starting from the nonlinear continuous dynamics in [3-DOF Rigid Body Dynamics](#3-dof-rigid-body-dynamics):

$$\frac{d\mathbf{x}}{dt} = \mathbf{f}(\mathbf{x}, \mathbf{u})$$

Linearize around operating point $(\mathbf{x}_0, \mathbf{u}_0)$:

$$\frac{d\Delta\mathbf{x}}{dt} \approx \mathbf{A}_c \Delta\mathbf{x} + \mathbf{B}_c \Delta\mathbf{u}$$

Where:

- $\Delta\mathbf{x} = \mathbf{x} - \mathbf{x}_0$: deviation from the operating point
- $\Delta\mathbf{u} = \mathbf{u} - \mathbf{u}_0$: control deviation
- $\mathbf{A}_c = \frac{\partial \mathbf{f}}{\partial \mathbf{x}}\big|_{\mathbf{x}_0}$: continuous-time state Jacobian
- $\mathbf{B}_c = \frac{\partial \mathbf{f}}{\partial \mathbf{u}}\big|_{\mathbf{x}_0}$: continuous-time input Jacobian

### Continuous Jacobians

For the satellite system the MPC Jacobians operate on the reordered state $\mathbf{x}_{\text{lin}} = [x, y, \theta, v_x, v_y, \omega]^T$. Only the mass and inertia appear because damping/disturbances are omitted:

| Symbol | Meaning | Value | Units | Code Reference |
| --- | --- | ----- | ----- | --- |
| $m$ | Total satellite mass  | 23.09 | kg | `SatelliteConfig.TOTAL_MASS` |
| $I$ | Moment of inertia | 0.324 | kg·m² | `SatelliteConfig.MOMENT_OF_INERTIA` |

**State Matrix $\mathbf{A}_c$:**

$$
\mathbf{A}_c = \begin{bmatrix}
0 & 0 & 0 & 1 & 0 & 0 \\
0 & 0 & 0 & 0 & 1 & 0 \\
0 & 0 & 0 & 0 & 0 & 1 \\
0 & 0 & 0 & 0 & 0 & 0 \\
0 & 0 & 0 & 0 & 0 & 0 \\
0 & 0 & 0 & 0 & 0 & 0
\end{bmatrix}
$$

Rows 1–3 encode the kinematics ($\dot{x} = v_x$, $\dot{y} = v_y$, $\dot{\theta} = \omega$) and the remaining rows are zero because the accelerations depend only on control inputs. This sparse $\mathbf{A}_c$ is what yields the constant discrete matrix shown in the next section.

**Input Matrix B_c:**

$\mathbf{B}_c \in \mathbb{R}^{6 \times 8}$ maps the eight thrusters to velocity and angular-velocity derivatives. Unlike $\mathbf{A}_c$, it depends on the current attitude because the thruster forces must be rotated from body frame to world frame:

$$
\mathbf{B}_c = \begin{bmatrix}
0 & \cdots & 0 \\
0 & \cdots & 0 \\
0 & \cdots & 0 \\
\cos\theta_1 / m & \cdots & \cos\theta_{8} / m \\
\sin\theta_1 / m & \cdots & \sin\theta_{8} / m \\
\tau_1 / I & \cdots & \tau_8 / I
\end{bmatrix}
$$

**Matrix Structure:**

Each column shows how one thruster affects the state:

- **Rows 1-3 (position and angle):** Zero, because thrusters affect only the accelerations
- **Rows 4-5 (linear acceleration):** Rotated thrust force divided by mass. For thruster $i$ with body-frame direction $\mathbf{d}_i^b = [d_x^b, d_y^b]^T$, we rotate to world frame using $\mathbf{R}(\theta)$ to get $[\cos\theta_i, \sin\theta_i]^T = \mathbf{R}(\theta) \mathbf{d}_i^b$
- **Row 6 (angular acceleration):** Torque $\tau_i = \mathbf{r}_i \times \mathbf{F}_i$ divided by moment of inertia $I$, where $\mathbf{r}_i$ is the thruster position

Since $\mathbf{B}_c(\theta)$ changes with angle, we must recompute it at each MPC step. This takes < 1 ms and doesn't slow down the 16.67 Hz control loop. The torque values $\tau_i$ are constant in body frame and precomputed from thruster geometry (see [Thruster Force Allocation](#thruster-force-allocation)).

### Discrete-Time Linearization (Euler Method)

With timestep $\Delta t = 0.06$ s we apply forward Euler to the simplified dynamics:

$$\mathbf{x}_{k+1} = \mathbf{x}_k + \Delta t \cdot \frac{d\mathbf{x}}{dt} = \mathbf{A}\mathbf{x}_k + \mathbf{B}\mathbf{u}_k$$

Because the only couplings are the kinematic relationships between $(x, y, \theta)$ and their respective velocities, $\mathbf{A}$ stays constant for every solve:

$$
\mathbf{A} =
\begin{bmatrix}
1 & 0 & 0 & \Delta t & 0 & 0 \\
0 & 1 & 0 & 0 & \Delta t & 0 \\
0 & 0 & 1 & 0 & 0 & \Delta t \\
0 & 0 & 0 & 1 & 0 & 0 \\
0 & 0 & 0 & 0 & 1 & 0 \\
0 & 0 & 0 & 0 & 0 & 1
\end{bmatrix}
$$

Rows 1–3 perform the integration of position and yaw angle, while rows 4–6 state that velocities remain unchanged unless a control input is applied.

The input matrix $\mathbf{B} \in \mathbb{R}^{6 \times 8}$ carries the thruster geometry. Only the velocity and angular-velocity rows are nonzero:

$$
\mathbf{B} =
\begin{bmatrix}
\mathbf{0}_{1 \times 8} \\
\mathbf{0}_{1 \times 8} \\
\mathbf{0}_{1 \times 8} \\
\frac{\Delta t}{m}\left[R(\theta)\,\mathbf{d}_{b,1} F_1\,\cdots\,R(\theta)\,\mathbf{d}_{b,8} F_8\right]_x \\
\frac{\Delta t}{m}\left[R(\theta)\,\mathbf{d}_{b,1} F_1\,\cdots\,R(\theta)\,\mathbf{d}_{b,8} F_8\right]_y \\
\frac{\Delta t}{I}\big[\tau_1\,\cdots\,\tau_8\big]
\end{bmatrix}
$$

where $R(\theta)$ rotates each body-frame direction $\mathbf{d}_{b,i}$ into world coordinates before dividing by the mass, and $\tau_i = \mathbf{r}_i \times (F_i \mathbf{d}_{b,i})$ is the precomputed body-frame torque for thruster $i$. `linearize_dynamics()` rebuilds this matrix every iteration so the world-frame force directions always match the current attitude.

**Parameters (how each term is built in code):**

- $\phi_i$: discrete body-frame directions pulled from `satellite_config.py`. Each thruster points along one of four axes (left/right/up/down), so the set of headings is {0°, 0°, 90°, 90°, 180°, 180°, 270°, 270°}.
- $\theta$: current world-frame yaw angle read from the state vector each MPC cycle.
- $\theta + \phi_i$: world-frame pointing angle of thruster $i$ after rotating the body-frame direction by the current attitude, and this is what feeds the $\cos$/$\sin$ terms in the velocity rows of $\mathbf{B}$.
- $\tau_i$: constant torque contribution for thruster $i$, precomputed once from geometry as $\mathbf{r}_i \times (F_i \mathbf{d}_i^b)$ (lever arm × body-frame force). These values live in `self.thruster_torques` so `linearize_dynamics()` can drop them directly into row 6.

**Example:** For thruster 1 with $\phi_1 = 0^\circ$ (points left in body frame), $F_1 = 0.441$ N, at satellite angle $\theta = 45^\circ$:

$$\mathbf{B}[3, 1] = \frac{0.06}{23.09} \cdot 0.441 \cos(45^\circ) \approx 8.1 \times 10^{-4} \text{ m/s}$$

$$\mathbf{B}[4, 1] = \frac{0.06}{23.09} \cdot 0.441 \sin(45^\circ) \approx 8.1 \times 10^{-4} \text{ m/s}$$

So at 45° the world-frame component of thruster 1 splits evenly between x and y, and the $\Delta t / m$ factor tells us the single-timestep velocity increment (≈0.81 mm/s in both axes) if that thruster fires for the whole MPC interval.

### Caching Strategy

Computing the rotation 𝐑(θ) and regenerating the Jacobians every solve costs a few hundred microseconds, so `linearize_dynamics()` keeps a small cache keyed by coarse attitude bins:

```python
cache_resolution = 0.01  # radians ≈ 0.57°
cache_key = int(theta / cache_resolution)
```

When the current angle falls into a bucket we’ve already computed, we reuse the stored (A, B) pair instead of recalculating it. If θ drifts into a new bucket we rebuild the matrices and update the cache. Quantizing at 0.01 rad (≈0.57°) keeps the approximation error small relative to our control bandwidth while avoiding redundant trigonometry and matrix fills.

### External Forces, Disturbances, and Noise

External influences (drag, valve delays, injected gusts, measurement noise) are **not** part of the matrices shown above. The MPC treats them as unmodeled disturbances that the receding-horizon updates will reject. Where they appear:

- **Hardware:** Actual drag/torques and sensor noise perturb the state before each solve. The solver still uses the simplified $A$/$B$ matrices, so the disturbances show up as deviations in the measured $\mathbf{x}_k$.
- **Simulation:** `testing_environment.py` adds damping, random forces, torque impulses, valve delay, and measurement noise *outside* the MPC linearization. After each integration step the noisy state is fed back into `simulation.py`, which then re-linearizes exactly as the hardware loop does.
- **Configuration knobs:** `SatelliteConfig.LINEAR_DAMPING_COEFF` and `SatelliteConfig.ROTATIONAL_DAMPING_COEFF` (defined in `config/physics.py`) control the linear/rotational drag that the simulator applies in `testing_environment.py:update_simulation()`. Real hardware inherently includes drag, and the simulator mirrors it by subtracting $c_d v$ and $c_r \omega$ externally before the next MPC call.

---

## Model Predictive Control Formulation

### Problem Statement

Every 60 ms we solve the finite-horizon optimal control problem below (see [Gurobi Formulation](#gurobi-formulation---explicit-problem-structure) for the exact MIQP setup):

$$\min_{\mathbf{u}} \sum_{j=1}^{N} \left\| \mathbf{x}_{k+j} - \mathbf{x}_{\text{target}} \right\|_Q^2 + \sum_{j=0}^{M-1} \left\| \mathbf{u}_{k+j} \right\|_R^2 + R_{\text{switch}} \sum_{j=0}^{M-1} \sum_{i=1}^{8} s_{j,i}$$

Subject to the discretized dynamics, binary thruster commands, and the state limits listed below. The initial column of the trajectory is always fixed to the current measurement.

### Horizons

- **Prediction Horizon (N = 12 steps = 0.72 seconds):**

  - Defines how far ahead we predict the motion.
  - Longer horizons improve look-ahead but performs worse in non-perfect environment with random external forces. 12 steps is the best compromise we measured.

- **Control Horizon (M = 12 steps = 0.72 seconds):**
  - Number of steps where thrusters are allowed to change.
  - After step M we freeze the control inputs.

### Cost Function (Objective)

**State Tracking Cost:**

$$J_{\text{track}} = \sum_{j=1}^{N} \left\| \mathbf{x}_{k+j|k} - \mathbf{x}_{\text{target}} \right\|_Q^2$$

$$= \sum_{j=1}^{N} \sum_{i=0}^{5} Q_{ii} (x_{k+j|k,i} - x_{\text{target},i})^2$$

Where Q is diagonal:

$$\mathbf{Q} = \text{diag}[Q_x, Q_y, Q_\theta, Q_{v_x}, Q_{v_y}, Q_\omega]$$

Default weights (`config/mpc_params.py`):

- **Q_x = Q_y = 1000**: keep waypoint error low.
- **Q_θ = 1000**: enforce heading alignment before docking.
- **Q_vx = Q_vy = 1750**: suppress residual drift near the target.
- **Q_ω = 1500**: bleed off spin quickly without over-shooting.

**Control Effort Cost:**

$$J_{\text{control}} = \sum_{j=0}^{M-1} \sum_{i=1}^{8} R_{ii} u_{j,i}^2$$

Using **R = 1.0** provides a small incentive to stay idle when possible without starving the controller.

**Switching Penalty (Optional):**

$$J_{\text{switch}} = R_{\text{switch}} \sum_{j=0}^{M-1} \sum_{i=1}^{8} s_{j,i}$$

Where $s_{j,i} = |u_{j,i} - u_{j-1,i}|$ (1 if thruster i toggles at step j).

**Total Objective:**

$$J = J_{\text{track}} + J_{\text{control}} + J_{\text{switch}}$$

### Constraints

1. **Dynamics:** $\mathbf{x}_{k+j+1} = \mathbf{A} \mathbf{x}_{k+j} + \mathbf{B} \mathbf{u}_{k+j}$ for $j = 0, \ldots, N-1$.
2. **Binary thrusts:** $u_{i,j} \in \{0, 1\}$ for all eight thrusters and each control step.
3. **State bounds:** $|x_j|, |y_j| \leq 3.0$ m, $|v_j| \leq 0.25$ m/s, $|\omega_j| \leq \pi/2$ rad/s, $|\theta_j| \leq 2\pi$ rad.
4. **Switching auxiliaries (optional):** $s_{j,i} \geq u_{j,i} - u_{j-1,i}$ and $s_{j,i} \geq u_{j-1,i} - u_{j,i}$ when $R_{\text{switch}} > 0$.

### Why This Works: Receding Horizon Principle

At 16.67 Hz we:

1. Measure $\mathbf{x}_k$ from OptiTrack or simulation.
2. Solve the N-step MIQP.
3. Apply only the first control action $u_k^*$.
4. Shift the horizon and repeat.

Because the plan is recomputed every cycle, the controller automatically rejects disturbances.

**Implementation notes**

- **Real hardware:** The MPC runs inside `real.py` with watchdog timers, and if a solve overruns we fall back to the proportional controller in `mpc.py` while continuing to stream telemetry/logs for post-flight analysis.
- **Simulation:** `simulation.py` shares the same controller instance so any behavioral difference comes from physics alone. This lets us A/B solver changes safely before deploying to hardware.

---

## Navigation Mathematics

**Implementation notes:** These helpers live in `navigation_utils.py` and run unmodified in both environments. The simulator feeds perfect geometry into them (unless noise is injected), while the hardware loop passes OptiTrack-derived positions and headings through the same functions inside `real.py`, `mission.py`, and `path_planning_manager.py`, so every angle-wrap edge case is exercised in both modes.

### Angle Normalization

Yaw angles wander outside [-π, π] whenever the vehicle spins multiple times, so we normalize back into that interval before feeding the values to the controller:

```python
def normalize_angle(angle):
    while angle > π:
        angle -= 2π
    while angle < -π:
        angle += 2π
    return angle
```

Alternative using `atan2` (preferred in code):

$$\text{normalize}(\theta) = \text{atan2}(\sin\theta, \cos\theta)$$

Why this matters:

- OptiTrack provides absolute angles that may be more than π rad apart, so subtracting them directly can suggest a needless full rotation.
- The MPC linearization is valid only when the angular error stays small.
- Wrapping both angles into [-π, π] ensures the controller commands the shortest physical turn.

### Shortest Angular Difference

Given current angle θ_current and target θ_target, the shortest rotation direction is:

$$\Delta\theta = \arctan2(\sin(\theta_{\text{target}} - \theta_{\text{current}}), \cos(\theta_{\text{target}} - \theta_{\text{current}}))$$

This keeps $\Delta\theta$ in [-π, π] so we always choose the shortest path.

**Example:** current = 170° ($2.967$ rad), target = -170° ($-2.967$ rad)

- Raw difference: -340° ($-5.934$ rad) — wraps the long way around the circle
- Equivalent shorter rotation: +20° ($+0.349$ rad) — go the short way
- The `atan2` formulation returns $+0.349$ automatically.

### Preventing the 270° Wrapping Issue

Common bug:

```python
# WRONG: Can cause 340° rotation at the -π/π boundary
target_angle = math.radians(-170)      # -170° ≈ -2.967 rad
current_angle = math.radians(170)      # +170° ≈ 2.967 rad
error = target_angle - current_angle   # -340° ≈ -5.934 rad (long way)
```

**Fix:** move the target into the same neighborhood as the current angle before computing the error:

```python
angle_diff = atan2(sin(target - current), cos(target - current))  # +20° ≈ +0.349 rad
target_adjusted = current + angle_diff  # In same neighborhood as current
```

`mpc.py` performs this adjustment near lines 516–518.

### Obstacle Clearance via Point-to-Line Distance

Guidance treats each move as a straight segment from the current position $\mathbf{A}$ to the next waypoint $\mathbf{B}$. The helper routine `point_to_line_distance()` measures how far an obstacle center $\mathbf{C}$ lies from that segment. If the clearance drops below the configured safety radius $R$, we create a detour waypoint next to the obstacle and command the MPC to visit it first, ensuring the final leg goes around the obstacle before reaching the original target.

**Distance computation**

1. Project $\mathbf{P}$ onto the infinite line through $\mathbf{A}$–$\mathbf{B}$:
$$\text{projection} = \frac{(\mathbf{P} - \mathbf{A}) \cdot (\mathbf{B} - \mathbf{A})}{\|\mathbf{B} - \mathbf{A}\|^2}$$
2. Clamp the projection to the segment limits:
$$\text{projection} = \max(0, \min(1, \text{projection}))$$
3. Recover the closest point on the segment:
$$\text{closest} = \mathbf{A} + \text{projection} \cdot (\mathbf{B} - \mathbf{A})$$
4. Distance from $\mathbf{P}$ to the segment:
$$\text{distance} = \|\mathbf{P} - \text{closest}\|$$

**Detour generation**

If $\text{distance} - R < 0$ for any obstacle center, guidance constructs an intermediate waypoint offset perpendicular to the segment at the obstacle location (roughly $1.2 R$ away). The resulting path becomes start → intermediate → target, guaranteeing clearance:

$$\mathbf{intermediate} = \mathbf{C} + \text{perpendicular} \times (R \times 1.2)$$

---

## Numerical Integration

### Discretization Method: Euler Forward

Simulation and MPC predictions both integrate the dynamics with the first-order Euler method:

$$\mathbf{x}_{k+1} = \mathbf{x}_k + \Delta t \cdot \dot{\mathbf{x}}_k$$

Where $\dot{\mathbf{x}}_k$ is the derivative at the current state.

**Advantages:**

1. **Easy computation:** to update the state we just compute the current accelerations once and multiply by the timestep. No matrix solves or multi-stage Runge-Kutta steps are needed, which keeps the physics loop light enough to run in real time.
2. **Predictable results:** with Euler, the exact same inputs produce the exact same state update every time. That determinism helps when replaying logs.

**Disadvantages:**

1. **Lower accuracy for bigger timesteps:** Euler assumes the derivative stays constant over the whole timestep. When $\Delta t$ is large, that assumption breaks and error grows with $\Delta t^2$, so distances and angles drift. Running the simulation at 0.005 s keeps these errors negligible.
2. **Can go unstable:** if the timestep is too large for the system dynamics (e.g., fast damping or rotation), the solution can “explode” numerically. To prevent that we keep the physics integrator on the short 0.005 s step even though the MPC loop operates at 0.06 s.

**Implementation in simulation.py:**

```python
# Current state derivative
state_derivative = compute_dynamics(state, forces)

# Euler step
state_new = state + dt * state_derivative
```

### Stability Consideration

For stable integration, the timestep must satisfy:

$$\Delta t < \frac{2}{\lambda_{\max}}$$

Where $\lambda_{\max}$ is the largest eigenvalue of matrix A. Because $A = I + \Delta t A_c$ for Euler discretization, its eigenvalues are $1 + \Delta t \lambda_i(A_c)$. In the current simplified model $A_c$ contains only kinematic couplings (zeros elsewhere), so every $\lambda_i(A_c) = 0$ and $A$ ends up with ones on the diagonal (i.e., $\lambda_{\max}(A) = 1 + 0$). The stability bound therefore reduces to $\Delta t < 2 / 1 = 2$ s, which our 0.005 s integrator easily satisfies.

### MPC's Discrete Model

The MPC uses the same forward-Euler discretization that drives the simulator:

$$\mathbf{A} = \mathbf{I} + \Delta t \mathbf{A}_c, \quad \mathbf{B} = \Delta t \mathbf{B}_c$$

- $\mathbf{A}_c$ and $\mathbf{B}_c$ come directly from `linearize_dynamics()` (continuous-time Jacobians).
- Multiplying by $\Delta t$ converts continuous derivatives into per-step increments, exactly matching how the simulator/hardware integrate at each control interval.
- Using the identical discretization in simulation and MPC keeps the controller's predictions and the plant behavior aligned, so there is no drift between the model used for optimization and the dynamics used for execution.

---

## Control Implementation Details

This section mirrors the control logic in `mpc.py` and related helpers, focusing on the features that were added in response to test behavior.

### Adaptive Velocity Weights

Close to the target we observed oscillations caused by residual velocity, so the controller temporarily boosts the velocity weights whenever the position error is under 0.25 m:

```python
pos_error = norm(x_current[:2] - x_target[:2])
if pos_error < DAMPING_ZONE:
    vel_magnitude = norm(x_current[3:5])
    if vel_magnitude > VELOCITY_THRESHOLD:
        boost_factor = min(3.0, MAX_VELOCITY_WEIGHT / Q_vel)
        Q_vel *= boost_factor  # Up to 3x increase
```

This trims overshoot by penalizing residual velocity until the vehicle settles.

### Warm Starting

We feed Gurobi the previous solution, shifted by one step, before each solve:

$$\mathbf{u}_{k}^{(t)} = \text{shift}(\mathbf{u}_{k-1}^{(t-1)}, 1) + \text{repeat}(\mathbf{u}_{k-1}^{(t-1)}[-1])$$

$$\mathbf{x}_{k}^{(t)} = \text{shift}(\mathbf{x}_{k-1}^{(t-1)}, 1) + \text{project\_dynamics}()$$

Benefits:

- Keeps thruster sequences smooth across cycles.
- Preserves useful structure for the branch-and-bound search.
- Improves convergence consistency (see [Convergence Rate Improvement](#convergence-rate-improvement)).

### Solver Parameters (Gurobi)

Key parameters tuned for real-time MPC:

| Parameter  | Value | Purpose |
| --- | --- | --- |
| MIPGap | 1e-2 (1%) | Stop once within 1% of optimality |
| MIPFocus | 1 | Bias toward feasible solutions quickly |
| Heuristics | 0.01 | Limit heuristic work to 1% of solver time |
| Cuts | 1 | Moderate cut generation |
| Presolve | 2 | Aggressive presolve to shrink the model |
| Threads | 1 | Single thread avoids overhead |
| TimeLimit  | 0.05 s | Hard deadline of 50 ms per solve |

The priority is predictable runtime rather than squeezing out the last 0.1% of optimality.

### Fallback Controller

If the MPC solve fails or exceeds the time limit, we fall back to the heuristic controller implemented in `_get_fallback_control()` inside `mpc.py`. It measures the position, velocity, and angle errors relative to the current target, then fires the thruster pair that reduces the dominant error component (±X, ±Y, or yaw). Thresholds from `config.mpc_params` keep the response conservative—just enough thrust to slow motion and keep heading reasonable until the next MPC solve succeeds.

---

## Derivation of Key Equations

The derivations below stay in the doc so we can re-derive parameters quickly when the hardware changes.

### Moment of Inertia from First Principles

For a rectangular block rotating about its center we start from the definition:

$$I = \int_{\text{area}} r^2 \, dm$$

With uniform density, $dm = \rho \, dA$ and $\rho = \frac{m}{L^2}$ for a square plate of side $L$. In Cartesian coordinates (rotation about Z-axis):

$$I = \rho \int_{-L/2}^{L/2} \int_{-L/2}^{L/2} (x^2 + y^2) \, dx \, dy$$

Evaluate the inner integral with respect to $y$:

$$\int_{-L/2}^{L/2} (x^2 + y^2) \, dy = x^2 L + \left[ \frac{y^3}{3} \right]_{-L/2}^{L/2} = x^2 L + \frac{L^3}{12}$$

Now integrate over $x$:

$$I = \rho \int_{-L/2}^{L/2} \left(x^2 L + \frac{L^3}{12}\right) dx = \rho \left[ \frac{L x^3}{3} + \frac{L^3}{12} x \right]_{-L/2}^{L/2} = \rho \left( \frac{L^4}{12} + \frac{L^4}{12} \right) = \rho \frac{L^4}{6}$$

Substitute $\rho = m / L^2$ to obtain:

$$I = \frac{1}{6} m L^2$$

With $m = 23.09$ kg, $L = 0.29$ m:

$$I = \frac{1}{6} \times 23.09 \times 0.29^2 = 0.324 \, \mathrm{kg \cdot m^2}$$

### Torque from Off-Center Forces

Start from the vector definition:

$$\boldsymbol{\tau} = \mathbf{r} \times \mathbf{F} = \det \begin{bmatrix} \mathbf{i} & \mathbf{j} & \mathbf{k} \\ r_x & r_y & 0 \\ F_x & F_y & 0 \end{bmatrix} = (0, 0, r_x F_y - r_y F_x)$$

Since motion is planar, only the z-component remains:

$$\tau = r_x F_y - r_y F_x$$

**Example:** Thruster 1 at $(0.145, 0.06)$ pushing left with $\mathbf{F} = [-F, 0]$:

$$\tau_1 = 0.145 \cdot 0 - 0.06 \cdot (-F) = 0.06 F$$

Positive $\tau$ corresponds to counter-clockwise rotation, matching the sign convention in `satellite_config.py`.

### Linearized State-Space Model

Starting from Newton’s laws in the world frame:

$$m \dot{\mathbf{v}} = \sum_{i=1}^{8} \mathbf{F}_{i,\text{world}}, \qquad I \dot{\omega} = \sum_{i=1}^{8} \tau_i$$

with kinematics $\dot{x} = v_x$, $\dot{y} = v_y$, $\dot{\theta} = \omega$. Order the MPC state as $\mathbf{x}_{\text{lin}} = [x, y, \theta, v_x, v_y, \omega]^T$.

Linearization steps:

1. Thruster forces in body frame: $\mathbf{F}_{i,\text{body}} = F_i \mathbf{d}_{b,i}$.
2. Rotate to world frame: $\mathbf{F}_{i,\text{world}} = R(\theta)\mathbf{F}_{i,\text{body}}$. Around the operating point we treat $\theta$ as constant for the small deviations, so $\partial \mathbf{F}_{i,\text{world}} / \partial \theta$ terms vanish.
3. Linear accelerations: $\dot{v}_x = \frac{1}{m} \sum_i F_{i,\text{world},x}$ and $\dot{v}_y = \frac{1}{m} \sum_i F_{i,\text{world},y}$.
4. Angular acceleration: $\dot{\omega} = \frac{1}{I} \sum_i \tau_i$ with $\tau_i = \mathbf{r}_i \times \mathbf{F}_{i,\text{body}}$ (body-frame quantities).

Collecting these derivatives yields the continuous matrices:

$$
\mathbf{A}_c =
\begin{bmatrix}
0 & 0 & 0 & 1 & 0 & 0 \\
0 & 0 & 0 & 0 & 1 & 0 \\
0 & 0 & 0 & 0 & 0 & 1 \\
0 & 0 & 0 & 0 & 0 & 0 \\
0 & 0 & 0 & 0 & 0 & 0 \\
0 & 0 & 0 & 0 & 0 & 0
\end{bmatrix}, \quad
\mathbf{B}_c =
\begin{bmatrix}
\mathbf{0}_{3 \times 8} \\
\frac{1}{m}\left[R(\theta)\,\mathbf{d}_{b,1} F_1\,\cdots\,R(\theta)\,\mathbf{d}_{b,8} F_8\right]_x \\
\frac{1}{m}\left[R(\theta)\,\mathbf{d}_{b,1} F_1\,\cdots\,R(\theta)\,\mathbf{d}_{b,8} F_8\right]_y \\
\frac{1}{I}[\tau_1\,\cdots\,\tau_8]
\end{bmatrix}
$$

Discretization with forward Euler gives $\mathbf{A} = \mathbf{I} + \Delta t \mathbf{A}_c$ and $\mathbf{B} = \Delta t \mathbf{B}_c$, matching the implementation in `linearize_dynamics()`.

### Angle Wrapping Formula

We need the shortest angular difference between target and current headings:

$$\Delta\theta = \operatorname{atan2}\left(\sin(\theta_{\text{target}} - \theta_{\text{current}}),\, \cos(\theta_{\text{target}} - \theta_{\text{current}})\right)$$

Derivation: represent angles as complex exponentials $e^{j\theta} = \cos\theta + j\sin\theta$. For $\delta = \theta_{\text{target}} - \theta_{\text{current}}$:

$$e^{j\delta} = \cos\delta + j\sin\delta$$

Any addition of $2\pi$ changes only the angle wrapped around the unit circle, not the coordinates. Taking $\operatorname{atan2}(\sin\delta, \cos\delta)$ recovers the principal argument in $[-\pi, \pi]$, giving the minimal rotation.

### Point-to-Line Distance (Obstacle Clearance)

Given start $\mathbf{A}$, end $\mathbf{B}$, and obstacle center $\mathbf{P}$, derive the perpendicular distance to the segment:

1. Vector along the path: $\mathbf{v} = \mathbf{B} - \mathbf{A}$.
2. Parameterize the line: $\mathbf{L}(t) = \mathbf{A} + t \mathbf{v}$.
3. Minimize $f(t) = \|\mathbf{P} - \mathbf{L}(t)\|^2 = \|\mathbf{P} - \mathbf{A} - t \mathbf{v}\|^2$. Differentiate: $\frac{df}{dt} = -2(\mathbf{P} - \mathbf{A} - t \mathbf{v}) \cdot \mathbf{v}$, set to zero, and solve: $t^\star = \frac{(\mathbf{P} - \mathbf{A}) \cdot \mathbf{v}}{\|\mathbf{v}\|^2}$.
4. Clamp to the segment: $\hat{t} = \max(0, \min(1, t^\star))$.
5. Closest point: $\mathbf{C} = \mathbf{A} + \hat{t} \mathbf{v}$.
6. Distance: $\text{dist} = \|\mathbf{P} - \mathbf{C}\|$.

This exact expression is implemented in `navigation_utils.point_to_line_distance()` for obstacle checking.

---

## Performance Metrics

### Solve Time Analysis

The solver must finish before the next 60 ms control tick:

$$t_{\text{solve}} < \Delta t_{\text{control}} = 0.06 \text{ s}$$

**Measured Performance (Simulation)**

We profiled three representative missions (8,233 solves total). All data comes from the physics simulator so we could sweep large numbers of runs:

| Test Type | Mean | Min | Max | Std Dev | p95 | Solves |
| --- | --- | --- | --- | --- | --- | --- |
| Point-to-Point Test 1 (0.5,0,90°→0,0,0°) | 3.10 ms | 1.50 ms | 12.00 ms | 1.14 ms | 4.39 ms | 383 |
| Point-to-Point Test 2 (2,2,180°→0,0,0°)  | 3.43 ms | 1.50 ms | 6.00 ms  | 1.02 ms | 5.30 ms | 653 |
| Circling Mission (return to start) | 3.41 ms | 1.50 ms | 14.70 ms | 0.83 ms | 4.20 ms | 3109 |

**Summary (recent sim vs hardware logs):**

- **Simulation avg/max:** 5.64 ms mean, 24.25 ms max (95th percentile 6.85 ms) across 3,301 solves.
- **Hardware avg/max:** 4.61 ms mean, 32.10 ms max (95th percentile 6.00 ms) across 3,270 solves.
- **Safety margin:** 60 ms control budget ÷ 32 ms worst-case ≈ 1.9× on hardware, so still real-time safe.
- **Timeout rate:** 0 / 6,571 combined runs, optimality gap ≤ 1% in all cases.

### Key Observations

1. Solve time stays comfortably under 5 ms even on long maneuvers.
2. Mission type has little effect on timing because the model size is fixed.
3. The maximum observed time is far below the 50 ms limit, leaving plenty of cushion.

### Conclusion

The controller meets the real-time budget with margin, so timing failures would more likely stem from the runtime environment than from the solver.

### Measured Performance (Simulation vs Real)

A single representative mission was flown on hardware and replayed in the simulator with identical controller settings. The comparison data comes from `Data/Comparison/Test/statistics.csv`:

| Metric | Real Test | Simulation | Absolute Error | Error % |
| --- | --- | --- | --- | --- |
| Position Error Mean (m) | 0.1791 | 0.2167 | 0.0376 | 20.99 |
| Position Error Std (m) | 0.1157 | 0.1253 | 0.0096 | 8.30 |
| Final Position Error (m) | 0.0241 | 0.0013 | 0.0228 | 94.61 |
| Angle Error Mean (deg) | 12.72 | 13.42 | 0.70 | 5.50 |
| Final Angle Error (deg) | 0.51 | 0.18 | 0.33 | 64.71 |
| Velocity Mean (m/s) | 0.0630 | 0.0642 | 0.0012 | 1.90 |
| Velocity Max (m/s) | 0.1267 | 0.1214 | 0.0053 | 4.18 |
| Final Velocity (m/s) | 0.0051 | 0.0006 | 0.0045 | 88.24 |
| Thruster T1 Duty (%) | 14.13 | 5.63 | 8.50 | 60.16 |
| Thruster T2 Duty (%) | 15.93 | 5.48 | 10.45 | 65.60 |
| Thruster T3 Duty (%) | 7.58 | 9.33 | 1.75 | 23.09 |
| Thruster T4 Duty (%) | 11.74 | 9.85 | 1.89 | 16.10 |
| Thruster T5 Duty (%) | 7.98 | 10.57 | 2.59 | 32.46 |
| Thruster T6 Duty (%) | 8.78 | 27.08 | 18.30 | 208.43  |
| Thruster T7 Duty (%) | 12.48 | 7.82 | 4.66 | 37.34 |
| Thruster T8 Duty (%) | 17.22 | 20.57 | 3.35 | 19.45 |
| Avg Thrusters Active | 0.96 | 0.96 | 0.00 | 0.00 |
| Total Thrust Usage (s) | 188.04 | 190.80 | 2.76 | 1.47 |
| Solve Time Mean (ms) | 4.61 | 5.64 | 1.03 | 22.34 |
| Solve Time Max (ms) | 32.10 | 24.25 | 7.85 | 24.45 |
| Test Duration (s) | 196.16 | 198.00 | 1.84 | 0.94 |

**Takeaways:**

- Position/orientation statistics remain within a few percent between real and simulated runs, the large percentage on “Final Position/Velocity” reflects the simulator’s frictionless settling vs. real hardware’s residual drag.
- Solver timing characteristics remain similar (4–6 ms averages), confirming that the simulated timing environment is representative of hardware.

The raw time-series used for this comparison live in `Data/Real_Test` and `Data/Simulation` (CSV logs), with the aggregate statistics under `Data/Comparison/Test/statistics.csv`.

### Control Authority

Thrusters set the hard limits on how quickly we can change the satellite’s velocity or rotation. Even with an aggressive cost function, the controller cannot accelerate faster than the combined thrust allows:

**Maximum linear acceleration:**

$$a_{\max} = \frac{F_{\text{colinear}}}{m} = \frac{0.9158}{23.09} \approx 0.040 \text{ m/s}^2$$

The numerator comes from the strongest pair of co-linear thrusters (5 & 6), whose calibrated forces sum to 0.9158 N.

**Maximum angular acceleration:**

$$\alpha_{\max} = \frac{\tau_{\text{aligned}}}{I} = \frac{0.1083}{0.324} \approx 0.33 \text{ rad/s}^2$$

Here $\tau_{\text{aligned}}$ is the sum of the four thrusters that produce positive torque simultaneously (1, 3, 5, 7). Any other combination yields an equal-magnitude negative torque.

These acceleration limits show up as state/velocity bounds inside the MPC so the optimizer never asks for a maneuver the hardware cannot deliver.

### Tracking Error Tolerance

Missions consider targets reached when:

- Position error < 0.05 m
- Angle error < 3° ≈ 0.052 rad
- Velocity < 0.05 m/s

---

## Gurobi Formulation - Explicit Problem Structure

### Standard Optimization Problem Form

The satellite MPC problem is formulated as a **Mixed-Integer Quadratic Program (MIQP)**:

$$\min_{\mathbf{u}, \mathbf{x}} J = \sum_{k=1}^{N} \left\| \mathbf{x}_k - \mathbf{x}_{\text{target}} \right\|_Q^2 + \sum_{k=0}^{M-1} \left\| \mathbf{u}_k \right\|_R^2$$

Subject to:

$$\mathbf{x}_{k+1} = \mathbf{A} \mathbf{x}_k + \mathbf{B} \mathbf{u}_k \quad \forall k = 0, \ldots, N-1$$

$$\mathbf{x}_0 = \mathbf{x}_{\text{current}}$$

$$\mathbf{u}_k \in \{0, 1\}^8 \quad \forall k = 0, \ldots, M-1$$

$$\underline{\mathbf{x}} \leq \mathbf{x}_k \leq \overline{\mathbf{x}} \quad \forall k = 0, \ldots, N$$

### Decision Variables

The model keeps the following variables:

- **Control variables**: $\mathbf{u} = [u_0, \ldots, u_{M-1}]$ with each $u_k \in \{0,1\}^8$ (12 × 8 = **96 binary variables**).
- **State variables**: $\mathbf{x} = [x_0, \ldots, x_N]$ with each $x_k \in \mathbb{R}^6$ (13 × 6 = **78 continuous variables**).
- **Optional switching variables**: another 96 binaries that only exist when $R_{\text{switch}} > 0$ (disabled in current missions).

So the current MIQP has 96 binary and 78 continuous variables.

### Gurobi Implementation Code Structure

Here's exactly how it's built in mpc.py:

```python
# Initialize Gurobi model
model = gp.Model("SatelliteMPC_Optimized")

# Create binary control variables
u_vars = []
for k in range(M):  # k = 0, 1, ..., 11 (12 steps)
    u_k = model.addVars(range(8), vtype=GRB.BINARY, name=f"u_{k}")
    u_vars.append(u_k)
# Result: u_vars[k][i] = thruster i at time k, i ∈ {0,1}

# Create continuous state variables with bounds
x_vars = []
state_lb = [-3.0, -3.0, -2π, -0.25, -0.25, -π/2]  # Lower bounds
state_ub = [+3.0, +3.0, +2π, +0.25, +0.25, +π/2]  # Upper bounds

for k in range(N+1):  # k = 0, 1, ..., 12 (13 time steps)
    x_k = model.addVars(range(6), lb=state_lb, ub=state_ub, name=f"x_{k}")
    x_vars.append(x_k)
# Result: x_vars[k][i] = state dimension i at time k, ∈ ℝ with bounds
```

### Constraint Structure

**1. Initial Condition Constraints (6 constraints total):**

```python
# x[0] = x_current (exactly)
for i in range(6):
    model.addConstr(x_vars[0][i] == x_current[i], name=f"init_{i}")
```

Mathematically:
$$x_{0,i} = x_{\text{current}, i} \quad \forall i \in \{0, 1, \ldots, 5\}$$

**2. Dynamics Constraints (N × 6 = 72 constraints total):**

```python
# x[k+1] = A @ x[k] + B @ u[k]
for k in range(N):  # k = 0, 1, ..., 11
    for i in range(6):  # state dimension
        # Linear combination: sum of A[i,j]*x[k][j]
        Ax_term = gp.quicksum(A[i, j] * x_vars[k][j] for j in range(6))
        # Linear combination: sum of B[i,j]*u[k][j]
        Bu_term = gp.quicksum(B[i, j] * u_vars[k][j] for j in range(8))
        # Constraint: x[k+1][i] = Ax + Bu
        model.addConstr(x_vars[k+1][i] == Ax_term + Bu_term,
                       name=f"dyn_{k}_{i}")
```

Mathematically, for each k and i:
$$x_{k+1,i} = \sum_{j=0}^{5} A_{ij} x_{k,j} + \sum_{j=0}^{7} B_{ij} u_{k,j}$$

**3. State Bound Constraints (Implicit in variable definitions):**

```python
# Already applied when creating variables with lb/ub
x_k = model.addVars(range(6), lb=state_lb, ub=state_ub, name=f"x_{k}")
```

### Objective Function Structure

The quadratic objective is built term-by-term:

```python
objective = 0

# State tracking cost: sum over all steps
for k in range(1, N+1):  # Note: k starts at 1, not 0
    for i in range(6):
        error = x_vars[k][i] - x_target[i]
        # Quadratic cost: Q[i,i] * error^2
        objective += Q_adaptive[i, i] * error * error

# Control effort cost
for k in range(M):
    for i in range(8):
        # Linear cost: R[i,i] * u[k][i]
        objective += R[i, i] * u_vars[k][i]

# Set objective (minimize)
model.setObjective(objective, GRB.MINIMIZE)
```

Mathematically:
$$J = \sum_{k=1}^{N} \sum_{i=0}^{5} Q_{ii} (x_{k,i} - x_{\text{target},i})^2 + \sum_{k=0}^{M-1} \sum_{i=0}^{7} R_{ii} u_{k,i} \;(+ R_{\text{switch}} \sum_{k=0}^{M-1} \sum_{i=1}^{8} s_{k,i})$$

### Constraint Matrix Sparsity

- **Constraints:** 6 initial + 72 dynamics = 78 (add 96 more only if switching is enabled, for 174 total).
- **Variables:** 96 binary + 78 continuous = 174 (add 96 switching binaries if needed, for 270 total).

The solver takes advantage of this block structure along the horizon, which is why solves finish in a few milliseconds even though MIQPs are NP-hard in theory.

---

## Integer Programming & Branch-and-Bound

### Why This is a Hard Problem (NP-Hard)

Because the thrusters are strictly on/off, the MPC problem becomes an MIQP. In theory these problems can take exponential time, but our structured model (short horizon, symmetric thrusters) keeps the search tree manageable.

### Binary vs Continuous Relaxation

If we allow $u_{k,i} \in [0,1]$, the problem becomes a convex QP and solves instantly, but the resulting “partial thrust” commands are not physically valid. Enforcing $u_{k,i} \in \{0,1\}$ keeps the solution feasible for the hardware.

### Branch-and-Bound Algorithm

Gurobi starts by solving the relaxed QP (thrusters allowed in [0,1]) to get a lower bound. If any thruster variable lands strictly between 0 and 1, it’s a branching candidate. The solver creates two subproblems—one with that thruster forced off, one with it forced on—and resolves the relaxed problem in each subproblem. Whenever a subproblem’s relaxed objective is already worse than the best integer solution found so far, that branch is pruned. This branch-and-bound search continues until we either prove optimality or hit the stopping criteria below.

The process stops once the gap

$$\frac{J^* - J_{\text{LB}}}{J^*}$$

drops below the configured MIPGap (1% here)

### Presolve and Cutting Planes

**Presolve (level 2):**

- Before branch-and-bound, Gurobi simplifies the model: it removes redundant bounds, fixes variables whose values are already implied by other constraints, and strips out empty rows/columns.
- In this MPC instance the full model has 174 variables and 78 constraints. Presolve usually fixes a couple dozen of them (e.g., states at known limits, redundant constraints), leaving a smaller core of roughly 150 variables and 70 constraints with ~1,000 non-zero coefficients.
- The smaller model saves a few milliseconds per solve because the solver doesn’t spend time on zeros or redundant rows.

**Cutting planes (Cuts = 1):**

- The relaxed LP/QP is a “shadow” of the true integer feasible set, so it can contain fractional corners that no binary solution ever visits. Cuts are extra inequalities that slice off those corners without removing any valid 0/1 point.
- Example: if $0 \le u_i, u_j \le 1$ and the relaxation allows $u_i + u_j \le 1.5$, adding $u_i + u_j \le 1$ removes the fractional combination $u_i = u_j = 0.75$ while keeping all binary pairs allowed by the original constraint.
- Tighter relaxations mean the lower bound sits closer to the true integer optimum, so branch-and-bound explores fewer subproblems.

## Linearization Error Bounds

### Taylor Series Expansion Error

When we linearize the nonlinear dynamics we keep only the first term of a Taylor expansion. The difference between the true dynamics and the linear model is governed by the next term in that expansion, which scales with the square of the state deviation:

$$\mathbf{f}(\mathbf{x}_0 + \Delta\mathbf{x}) = \mathbf{f}(\mathbf{x}_0) + \mathbf{J}(\mathbf{x}_0) \Delta\mathbf{x} + \frac{1}{2} \mathbf{H}(\mathbf{x}_0) (\Delta\mathbf{x})^2 + \ldots$$

Here $\mathbf{J}$ is the Jacobian we use in the linear model and $\mathbf{H}$ represents the higher-order curvature terms that become the approximation error. The largest source of curvature in this system is the rotation matrix that converts body-frame forces into world-frame forces.

If we change the angle by $\Delta\theta$, the rotation matrix can be approximated as:

$$\mathbf{R}(\theta + \Delta\theta) \approx \mathbf{R}(\theta) + \frac{d\mathbf{R}}{d\theta}\Delta\theta + \frac{1}{2}\frac{d^2 \mathbf{R}}{d\theta^2} (\Delta\theta)^2$$

Our linear model keeps only the first derivative term, so the neglected piece (and therefore the error) grows with $(\Delta\theta)^2$. Telemetry from hardware/sim runs shows that over a 60 ms control tick the attitude typically changes less than 0.05 rad. Using the Taylor remainder for the rotation matrix, the worst-case force error contributed by the second derivative is

$$\Delta F_{\text{max}} \le \frac{1}{2} F_{\text{pair}} (\Delta\theta)^2$$

where $F_{\text{pair}}$ is the combined magnitude of the strongest co-linear thruster pair. Thrusters 5 and 6 (adjacent and pointing in the same direction) sum to ≈0.92 N, so with $\Delta\theta = 0.05$ rad:

$$\Delta F_{\text{max}} \le \frac{1}{2} \cdot 0.92 \cdot 0.05^2 \approx 1.1 \times 10^{-3} \text{ N}$$

Even a larger-than-usual step of 0.1 rad in a single 60 ms control interval only yields ≈0.0046 N of error (or ≈0.08 N·m if four evenly-spaced thrusters produce torque simultaneously), still small compared to the damping/model-mismatch margin. Only repeated angle jumps beyond ~0.1 rad every step would make the linear approximation fall apart; otherwise the controller re-linearizes around the latest state on the next 60 ms update so errors don’t accumulate. If every step did incur ≥0.1 rad swings (e.g., sudden target jumps or rapid spin), the A/B matrices would no longer capture the actual dynamics and the MPC predictions would drift, so you’d need a shorter control interval or explicitly keep higher-order Taylor terms (i.e., move toward a nonlinear model).

### Bounding the Error (Why the Quadratic Approximation Works)

The force in world frame depends on angle:
$$F_x(\theta) = F_{b,x} \cos\theta - F_{b,y} \sin\theta$$

Linearization around $\theta_0$:
$$F_x(\theta_0 + \Delta\theta) \approx F_{b,x} \cos\theta_0 - F_{b,y} \sin\theta_0 + (F_{b,x} \sin\theta_0 - F_{b,y} \cos\theta_0) \Delta\theta$$

True vs linearized:
$$\Delta F_x = F_x(\theta_0 + \Delta\theta) - \hat{F}_x(\theta_0 + \Delta\theta)$$

The Taylor remainder tells us that the difference between the true and linearized forces obeys:

$$|\Delta F_x| \leq \frac{1}{2} \max_{\theta} \left|\frac{d^2F_x}{d\theta^2}\right| (\Delta\theta)^2$$

Because each thruster’s body-frame force components are below about 0.5 N, the second derivative can’t exceed the same order of magnitude. Plugging that into the remainder formula yields:

$$|\Delta F_x| \leq 0.35 (\Delta\theta)^2 \text{ N}$$

So for a 0.05 rad step, the X-force error is under $0.35 \times 0.05^2 \approx 9 \times 10^{-4}$ N, and even for a 0.1 rad step it stays below ≈$3.5 \times 10^{-3}$ N.

### Practical Error Estimates

Using the bound above:

- Δθ = 0.01 rad (~0.6°) → force error < $3.5 \times 10^{-5}$ N.
- Δθ = 0.05 rad (~2.9°) → force error < $8.8 \times 10^{-4}$ N.
- Δθ = 0.10 rad (~5.7°) → force error < $3.5 \times 10^{-3}$ N (≈0.4% of the strongest co-linear pair’s thrust, and still below any combination we command).

These bounds apply to a single 60 ms step; on the next MPC cycle we re-linearize around the updated state, so the per-step error doesn’t accumulate unless Δθ stays large every step.

For reference, a single thruster produces ~0.45 N and the strongest co-linear pair produces ~0.92 N, so even the 0.1 rad case is still well below the available thrust. Because we re-linearize every 60 ms and typical Δθ stays under 0.05 rad, the practical errors remain small.

### When Linearization Fails

Breakdowns are rare but can happen when:

1. **Δθ > 0.2 rad in a single step** – requires an extreme maneuver beyond our command bounds.
2. **Large angular velocities:** at ω = π/2 rad/s, a 0.06 s step produces Δθ ≈ 0.3 rad and the error climbs quickly, which is why the model assumes angular velocity stays within a reasonable range.
3. **Stale predictions:** by the end of a long horizon the predicted angle can drift from reality, but we re-linearize every 60 ms so accumulated error stays under control.
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

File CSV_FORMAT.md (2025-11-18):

# CSV Data Format Reference

Both simulation and real hardware produce identical CSV format for easy comparison.

## Output Files

Each mission run generates two CSV files:

1. **Detailed Data Log**: `simulation_data.csv` or `real_test_data.csv`
   - Full control loop data with all state variables, MPC info, and commands
   - 45 columns per row (see below)
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

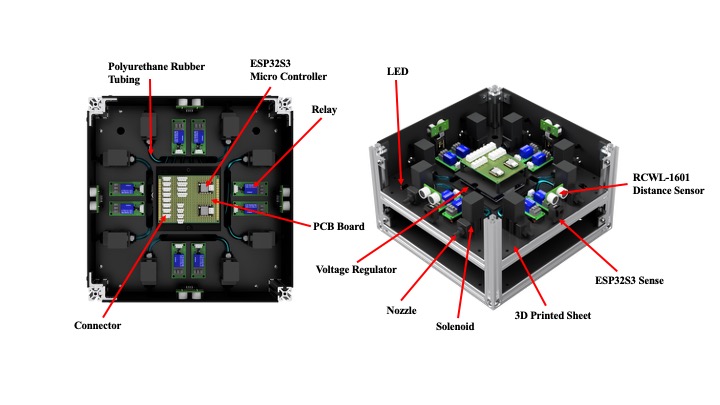
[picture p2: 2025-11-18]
images/satellite_2nd_level.jpg

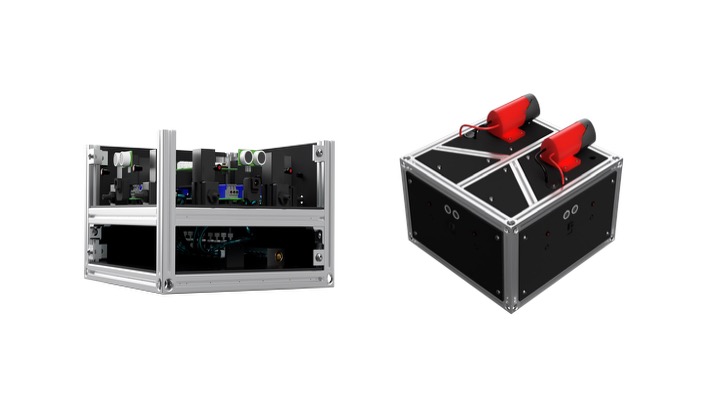
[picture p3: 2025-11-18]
images/satellite_1.jpg

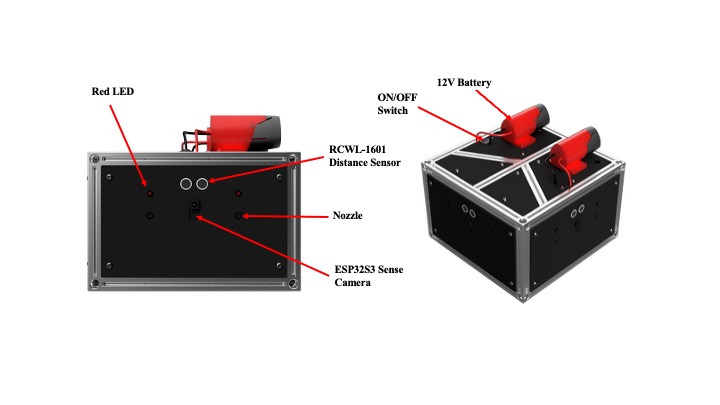
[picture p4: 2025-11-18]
images/satellite_2.jpg

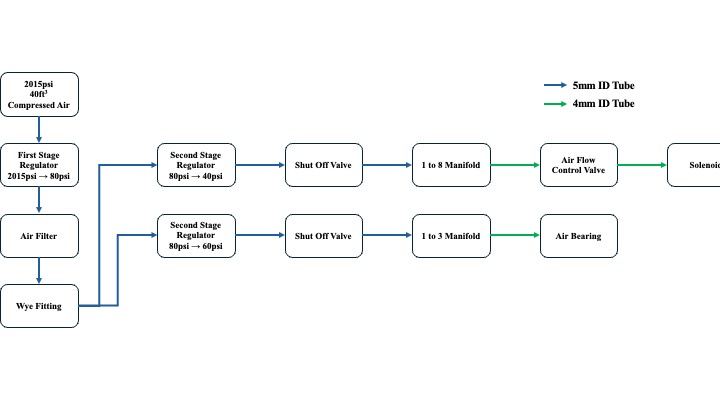
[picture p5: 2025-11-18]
images/airflow_diagram.jpg

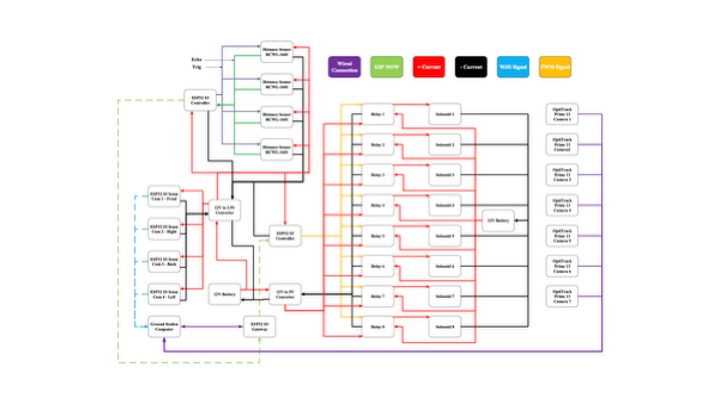
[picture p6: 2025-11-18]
images/electrical_diagram.jpg

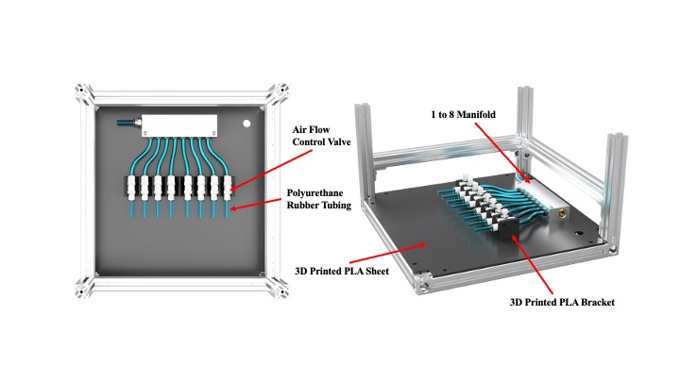
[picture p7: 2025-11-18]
images/satellite_1st_level.jpg

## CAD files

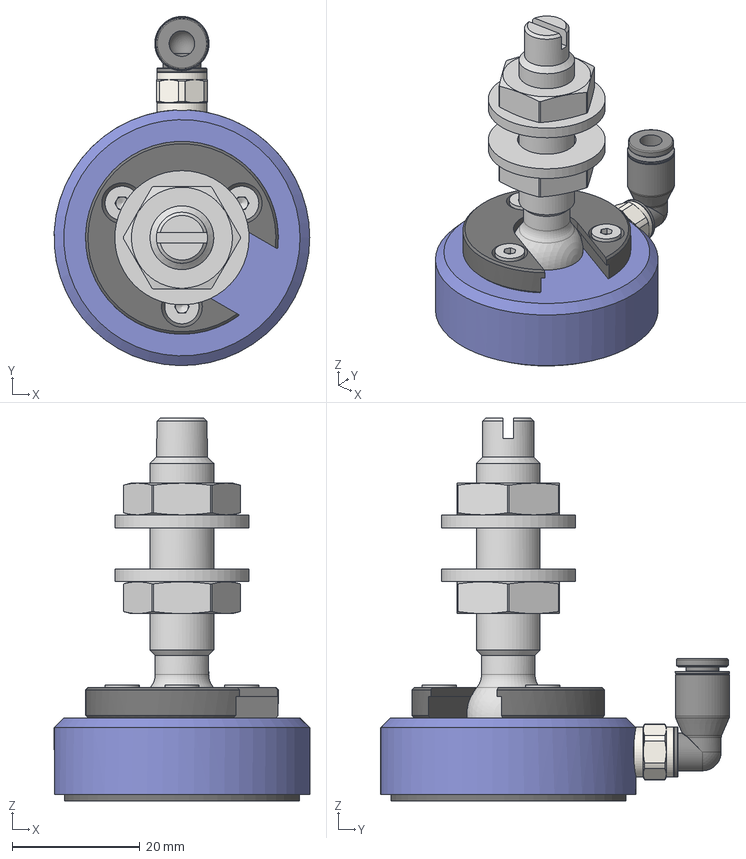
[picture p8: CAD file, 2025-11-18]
Cad_Files/Hardware/Air Bearing/Air Bearing Assembly.step
40.0 x 54.6 x 59.9 mm
S8013B05_S8013B05
S80XXNXX_S8010N03 x 2
S92FS01 x 2
S104001
S8013S02_S8013S01
Socket Countersunk Head Screw_AM_B18.3.5M - 3 x 0.5 x 8 Socket FCHS -- 8N x 3
5225K563_Push-to-Connect Tube Fitting for Air

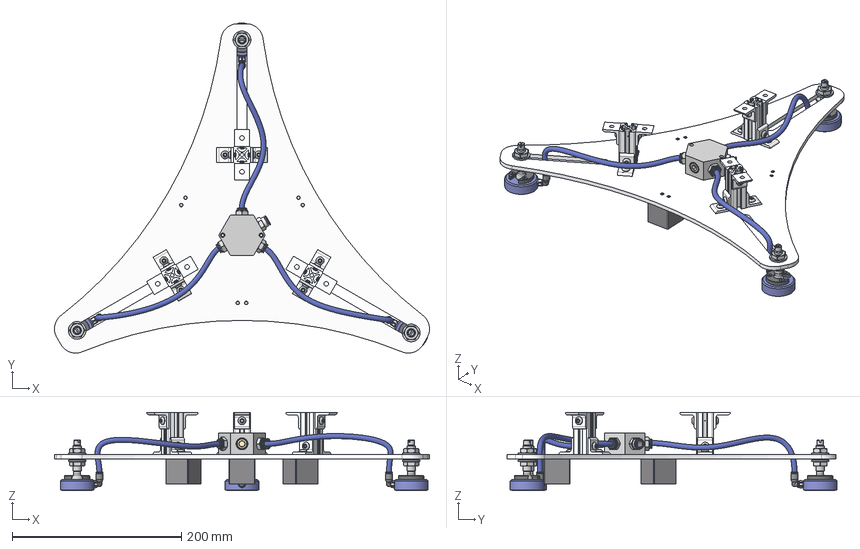
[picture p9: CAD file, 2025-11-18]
Cad_Files/Platform/Bot Assembly.step
443.3 x 390.3 x 92.7 mm
5537T104_T-Slotted Framing x 3
5537T935_T-Slotted Framing x 12
Base
Stand Mount x 3
S8013B05_S8013B05 x 3
S80XXNXX_S8010N03 x 6
S92FS01 x 6
S104001 x 3
S8013S02_S8013S01 x 3
Socket Countersunk Head Screw_AM_B18.3.5M - 3 x 0.5 x 8 Socket FCHS -- 8N x 9
5225K563_Push-to-Connect Tube Fitting for Air x 3
3490N159_Low-Profile Hex Manifold
50785K213_High-Pressure Brass Pipe Fitting x 2
5225K713 x 3
92095A206_Button Head Hex Drive Screw x 18
97715A622_Brass Button Head Hex Drive Screws x 6
51305K307_Push-to-Connect Tube Fitting with Universal Thread

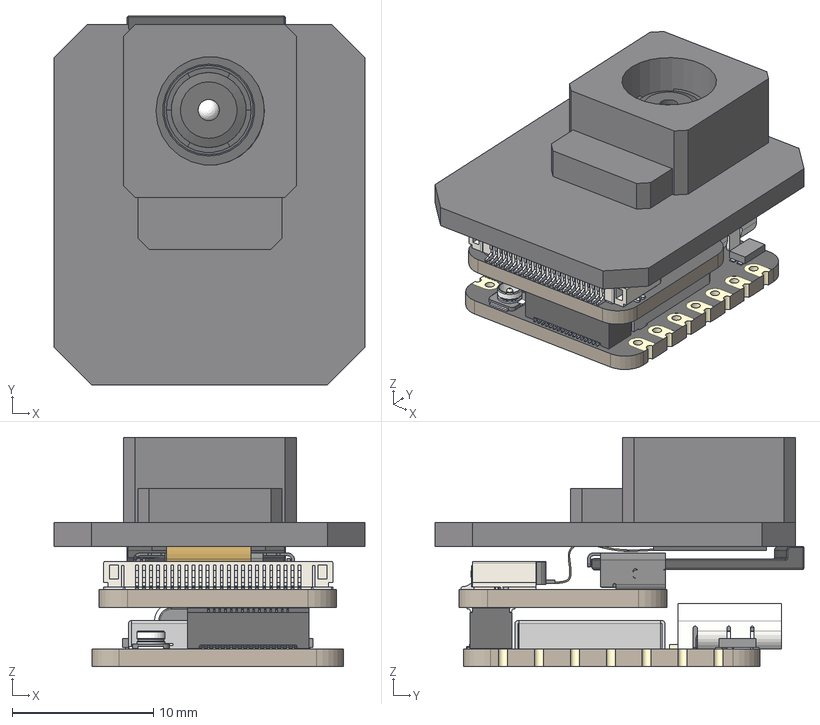
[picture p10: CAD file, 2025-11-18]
Cad_Files/Electronics/Xiao ESP32S3 Sense Assembly.step
22.0 x 26.1 x 16.2 mm
object_id_1
part_object_id_1_1
BOSS-EXTRUDE14_8_
BOSS-EXTRUDE7_4_
BOSS-EXTRUDE7_3_
BOSS-EXTRUDE14_4_
BOSS-EXTRUDE14_2_
BOSS-EXTRUDE14_11_
BOSS-EXTRUDE7_7_
BOSS-EXTRUDE14_9_
BOSS-EXTRUDE14_3_
BOSS-EXTRUDE14_7_
MIRROR2
BOSS-EXTRUDE14_5_
BOSS-EXTRUDE14_12_
BOSS-EXTRUDE7_8_
BOSS-EXTRUDE7_1_
BOSS-EXTRUDE14_10_
BOSS-EXTRUDE7_9_
BOSS-EXTRUDE14_6_
BOSS-EXTRUDE14_1_
BOSS-EXTRUDE7_6_
BOSS-EXTRUDE7_2_
CUT-EXTRUDE5
BOSS-EXTRUDE7_5_
Shield
Pins x 2
U.FL-R-SMT-1_10_ v1
DF40C-30DP-0.4V_51_ v1
DF40HC(3.0)-30DS
10067099-200LF v1
PCB
MicroSD v2
JUSHUO AFC01-S24FCA-00
Camer Module

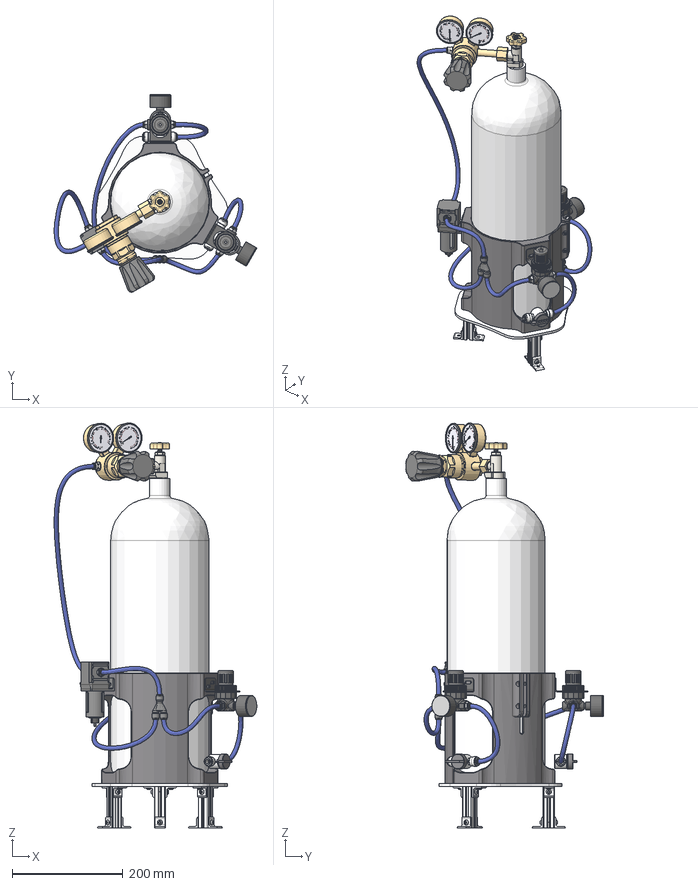
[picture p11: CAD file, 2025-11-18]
Cad_Files/Platform/Top Assembly.step
365.8 x 356.5 x 730.8 mm
5537T935_T-Slotted Framing x 12
Top
5537T104_T-Slotted Framing x 3
Tank Mount
40ft3 Air Cyllinder 2015 psi
77445A61
9891K66_Mounting Bracket for 1 8 and 1 4 NPT Regulator x 2
5225K713 x 6
4503K12_Polypropylene On Off Valve for Drinking Water x 2
92095A206_Button Head Hex Drive Screw x 12
92095A212_Button Head Hex Drive Screw x 6
REGULATOR AMMONIA_1
regulator adaptor
regulator adaptor 1
regulator pres x 2
51305K307_Push-to-Connect Tube Fitting with Universal Thread
5225K89_Push-to-Connect Tube Fitting for Air

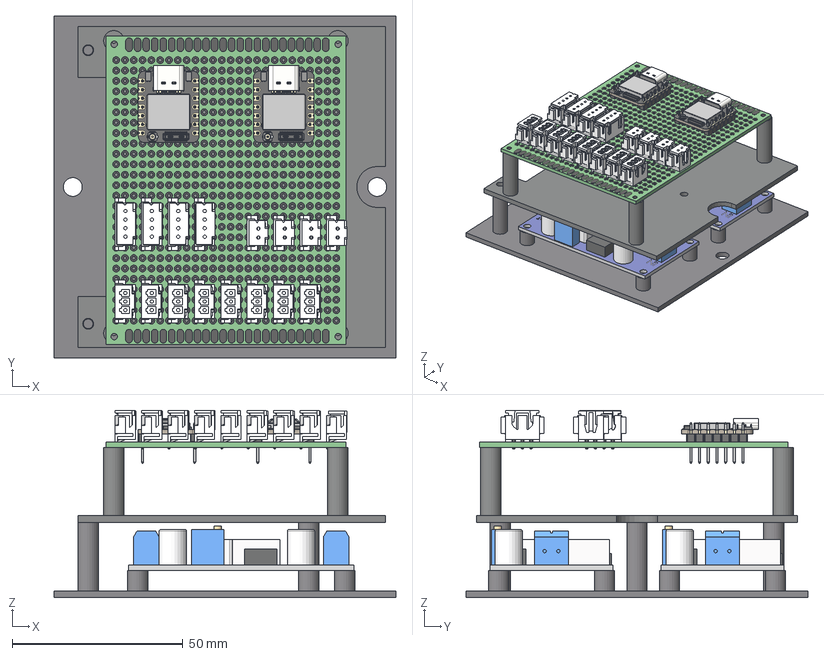
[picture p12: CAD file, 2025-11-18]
Cad_Files/Electronics/Electric Box Assembly.step
100.0 x 100.0 x 54.8 mm
Electric Base Plate
LM2596 DC-DC Buck Converter x 2
Electric Middle Plate
maketnaya_plata_7X9cm
BOSS-EXTRUDE14_8_ x 2
BOSS-EXTRUDE7_4_ x 2
BOSS-EXTRUDE7_3_ x 2
BOSS-EXTRUDE14_4_ x 2
BOSS-EXTRUDE14_2_ x 2
BOSS-EXTRUDE14_11_ x 2
BOSS-EXTRUDE7_7_ x 2
BOSS-EXTRUDE14_9_ x 2
BOSS-EXTRUDE14_3_ x 2
BOSS-EXTRUDE14_7_ x 2
MIRROR2 x 2
BOSS-EXTRUDE14_5_ x 2
BOSS-EXTRUDE14_12_ x 2
BOSS-EXTRUDE7_8_ x 2
BOSS-EXTRUDE7_1_ x 2
BOSS-EXTRUDE14_10_ x 2
BOSS-EXTRUDE7_9_ x 2
BOSS-EXTRUDE14_6_ x 2
BOSS-EXTRUDE14_1_ x 2
BOSS-EXTRUDE7_6_ x 2
BOSS-EXTRUDE7_2_ x 2
CUT-EXTRUDE5 x 2
BOSS-EXTRUDE7_5_ x 2
Shield x 2
Pins x 4
U.FL-R-SMT-1_10_ v1 x 2
DF40C-30DP-0.4V_51_ v1 x 2
7-Pin Header - Male - 2.54mm x 4
XHP-3 x 8
2Pin Female x 4

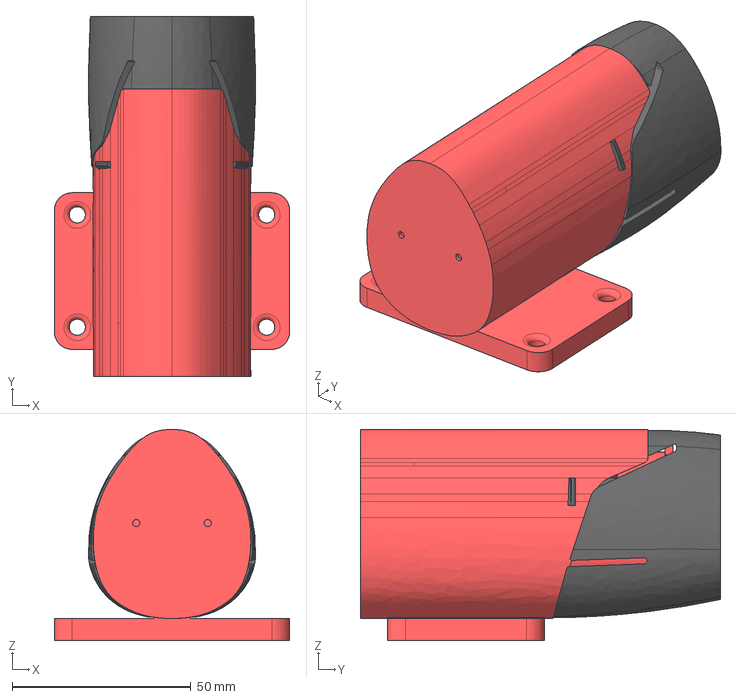
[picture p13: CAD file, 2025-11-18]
Cad_Files/Electronics/Battery Assembly.step
65.9 x 100.7 x 59.1 mm
Milwalukee M12 drill battery - case 8-30-18
M12 Batt Socket R03

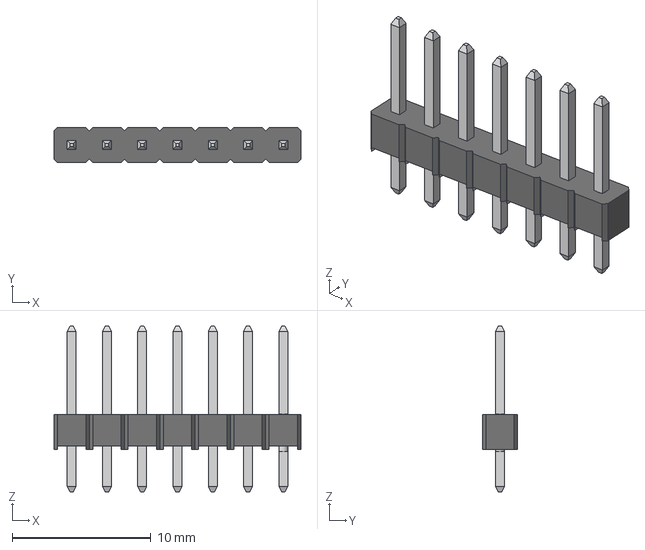
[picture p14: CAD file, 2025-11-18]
Cad_Files/Electronics/Header Pins/7-Pin Header - Male - 2.54mm.step
17.8 x 2.54 x 11.9 mm

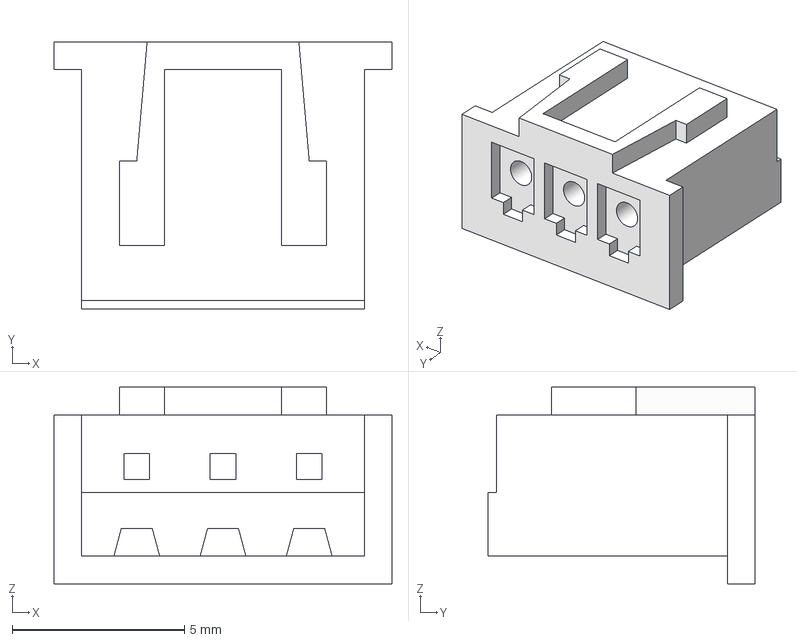
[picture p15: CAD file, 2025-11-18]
Cad_Files/Electronics/JST-XH Connectors/XHP-3.step
9.80 x 7.75 x 5.70 mm

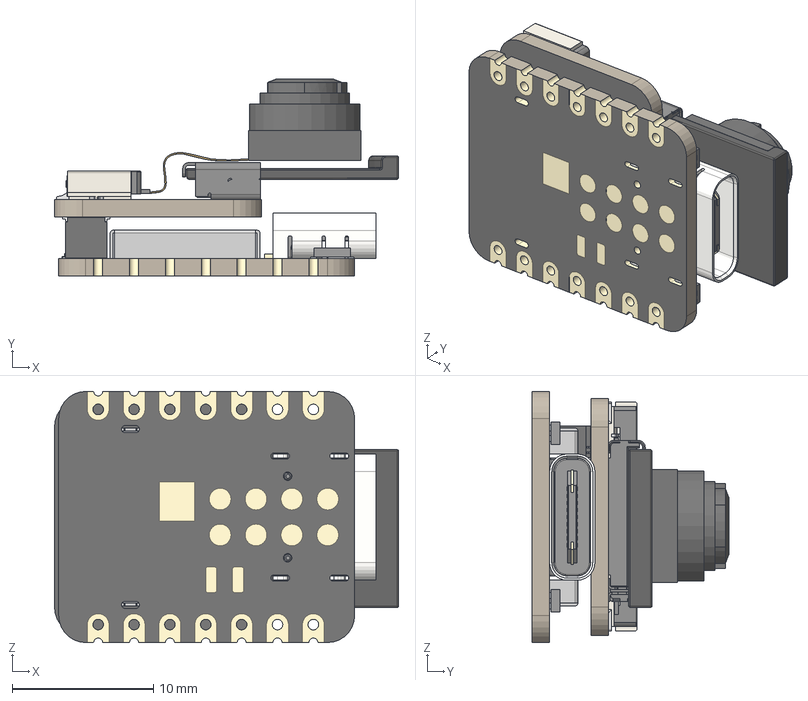
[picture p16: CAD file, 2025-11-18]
Cad_Files/Electronics/Seeed Studio XIAO-ESP32-S3-Sense.step
24.4 x 14.0 x 17.8 mm
BOSS-EXTRUDE14_8_
BOSS-EXTRUDE7_4_
BOSS-EXTRUDE7_3_
BOSS-EXTRUDE14_4_
BOSS-EXTRUDE14_2_
BOSS-EXTRUDE14_11_
BOSS-EXTRUDE7_7_
BOSS-EXTRUDE14_9_
BOSS-EXTRUDE14_3_
BOSS-EXTRUDE14_7_
MIRROR2
BOSS-EXTRUDE14_5_
BOSS-EXTRUDE14_12_
BOSS-EXTRUDE7_8_
BOSS-EXTRUDE7_1_
BOSS-EXTRUDE14_10_
BOSS-EXTRUDE7_9_
BOSS-EXTRUDE14_6_
BOSS-EXTRUDE14_1_
BOSS-EXTRUDE7_6_
BOSS-EXTRUDE7_2_
CUT-EXTRUDE5
BOSS-EXTRUDE7_5_
Shield
Pins x 2
U.FL-R-SMT-1_10_ v1
DF40C-30DP-0.4V_51_ v1
DF40HC(3.0)-30DS
10067099-200LF v1
PCB
MicroSD v2
JUSHUO AFC01-S24FCA-00
Camer Module

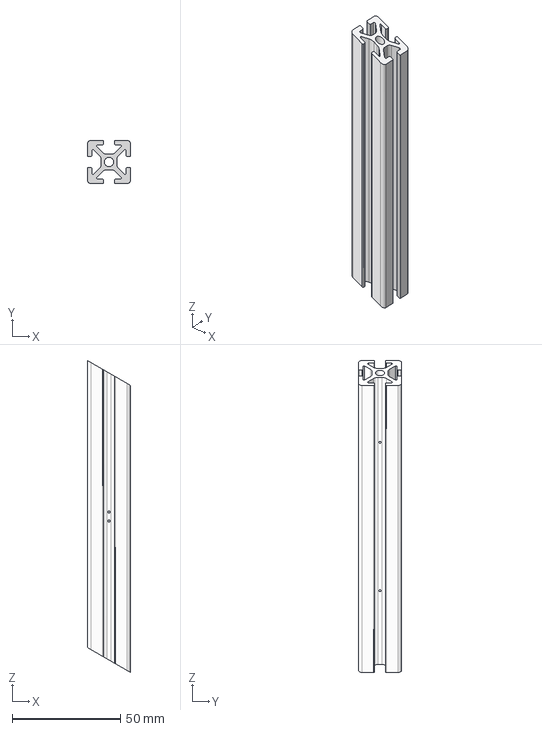
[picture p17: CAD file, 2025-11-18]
Cad_Files/Hardware/Aluminum Extrsuion Parts/144.3mm Aluminum Extrusion 2020 - Cross.step
20.0 x 20.0 x 144.3 mm

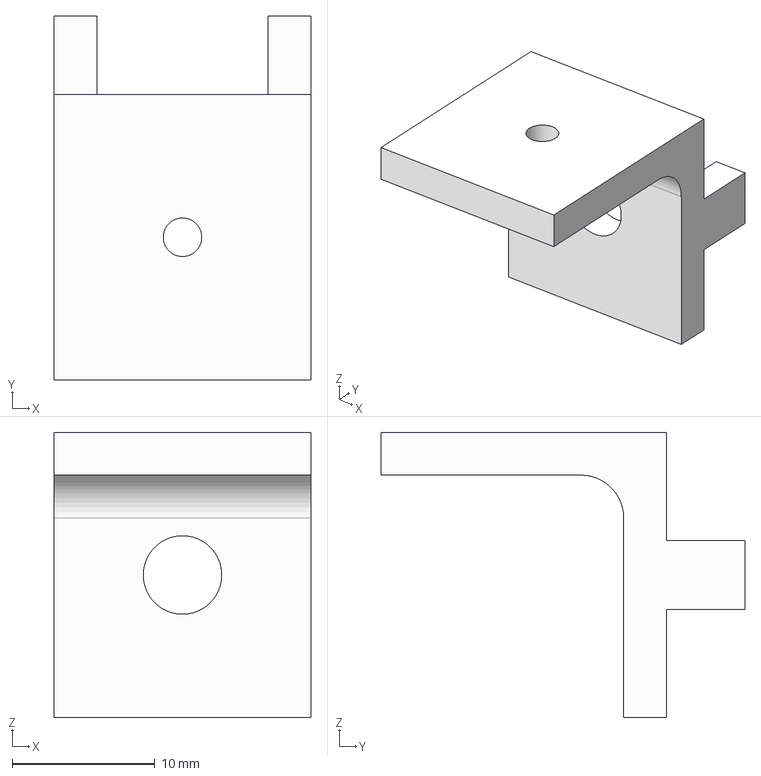
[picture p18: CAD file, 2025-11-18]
Cad_Files/Hardware/Covers/Cover Mount 10mm (~recovered).step
18.0 x 25.5 x 20.0 mm

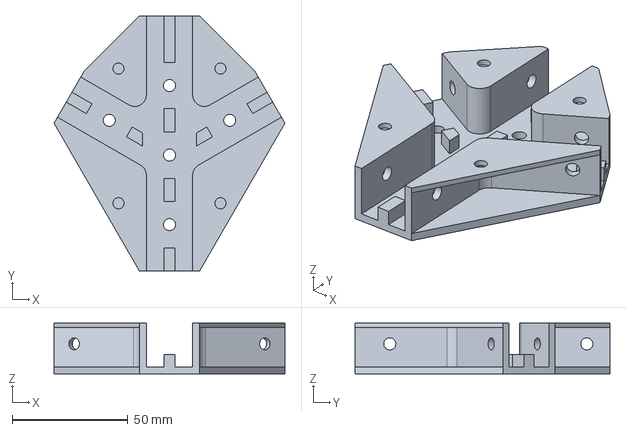
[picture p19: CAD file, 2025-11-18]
Cad_Files/Hardware/Cross Brace.step
99.6 x 110.0 x 22.0 mm

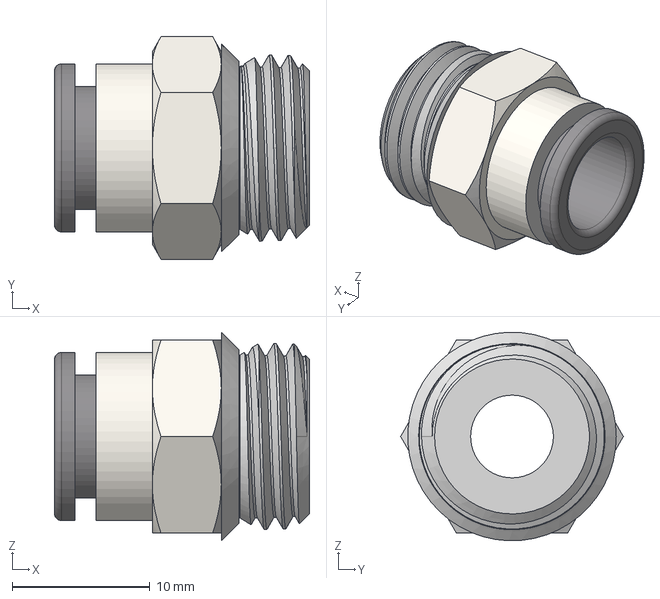
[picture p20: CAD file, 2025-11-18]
Cad_Files/Hardware/Push to Connect Fittings/1,,4 NPT to 8mm.step
18.5 x 16.2 x 15.1 mm

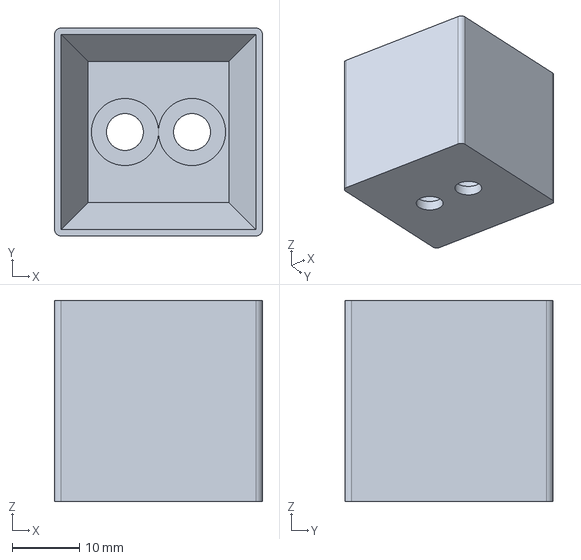
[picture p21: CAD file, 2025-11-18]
Cad_Files/Platform/Stand Mount.step
31.0 x 31.0 x 30.0 mm

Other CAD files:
Cad_Files/Satellite/Middle Plate.step
Cad_Files/Stand/250mm - 20mm Aluminum Extrusion Cross Top.step
DXF/DXF_Files/Shape3.dxf
Cad_Files/Electronics/JST-XH Connectors/JST - XH - SMD (R) - 4Pin - 2.54mm.step
Cad_Files/Electronics/1-channel relay board 3D.step
Cad_Files/Electronics/21mm round on-off switch.step
Cad_Files/Electronics/6mm led indicator RED.step
Cad_Files/Electronics/JST-XH Connectors/JST - XH - SMD (R) - 2Pin - 2.54mm.step
Cad_Files/Electronics/JST-XH Connectors/JST - XH - SMD (R) - 3Pin - 2.54mm.step
Cad_Files/Electronics/JST-XH Connectors/JST XHP-2 Housing.step
Cad_Files/Electronics/JST-XH Connectors/JST XHP-4.step
Cad_Files/Electronics/LED - 12mm - RED.step
Cad_Files/Electronics/LM2596 DC-DC Buck Converter.step
Cad_Files/Electronics/M12 Battery Adapter.step
Cad_Files/Electronics/Milwaukee M12 battery.step
Cad_Files/Electronics/Milwaukee M12 drill battery - case.step
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

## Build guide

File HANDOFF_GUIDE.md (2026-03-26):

# Handoff Guide for Next Project Lead

**This document is for the person/team taking over the satellite project after the initial build.**

If you're reading this, this guide ensures you can operate it safely and maintain it properly.

---

## Table of Contents

- [First Week Checklist](#first-week-checklist)
- [System Health Verification](#system-health-verification)
- [Critical Information](#critical-information)
- [Maintenance Schedule](#maintenance-schedule)
- [Hardware Quirks & Workarounds](#hardware-quirks--workarounds)
- [Common Failures & Solutions](#common-failures--solutions)
- [Important Contacts](#important-contacts)
- [Documentation You'll Use Most](#documentation-youll-use-most)
- [Recording Your Own Knowledge](#recording-your-own-knowledge)

---

## First Week Checklist

### Setup and Verification

- [ ] **Get Gurobi License**
  - Go to: https://www.gurobi.com/academia/academic-program-and-licenses/
  - Register with your academic `.edu` email
  - Download `gurobi.lic` and keep it local only
  - Placing it in the project root is supported and gitignored
  - Verify: `python3 -c "import gurobipy; print('OK')"`

- [ ] **Install dependencies**
  ```bash
  pip install -r requirements.txt
  pip install pytest pytest-cov
  ```

- [ ] **Run simulation (no hardware needed)**
  ```bash
  python3 simulation.py
  # Select: 1. Waypoint Navigation
  # Enter waypoints: (0, 0), (1, 0), (1, 1)
  # Watch it execute—this proves the code works
  ```

- [ ] **Read critical docs**
  - [README.md](README.md) - Project overview
  - [ARCHITECTURE.md](ARCHITECTURE.md) - Architecture overview
  - [HARDWARE_TEST_PROCEDURE.md](HARDWARE_TEST_PROCEDURE.md) - Safety procedures
  - This handoff guide

### Hardware Verification

- [ ] **Physical Inspection**
  - [ ] Check for visible damage on satellite (thrusters, air bearings, markers)
  - [ ] Verify all 8 thrusters are securely mounted
  - [ ] Confirm 3 air bearings are securely attached to satellite underside
  - [ ] Check reflective markers are clean and securely attached

### Baseline Establishment

- [ ] **Quick Thruster Verification**
  ```bash
  cd Thruster_Test
  python3 thruster_test.py
  ```
  Fires each thruster 1-8 sequentially for 1 second.
  Quick sanity check that all thrusters respond and work before testing.

- [ ] **Thruster Recalibration** (STRONGLY RECOMMENDED)
  - [ ] Follow [THRUSTER_CALIBRATION.md](THRUSTER_CALIBRATION.md)

  This measures actual thruster forces and updates config.
  Takes ~1.5 hours.

- [ ] **Run Full Simulation Test**
  ```bash
  python3 simulation.py
  # Run through 2-3 complete missions
  # Verify performance is reasonable
  ```

- [ ] **Run First Hardware Mission**
  - [ ] Follow [HARDWARE_TEST_PROCEDURE.md](HARDWARE_TEST_PROCEDURE.md)

  ```bash
  python3 real.py
  # Start with simple waypoint (0,0) → (0.5, 0)
  # Verify it completes successfully
  ```

---

## System Health Verification

After completing the first week checklist, you should verify the overall system health:

### Software Health Check

```bash
# Run complete test suite
pytest -v

# Expected result: All tests should pass
# If tests fail: Review TROUBLESHOOTING.md
```

### Simulation Performance Baseline

```bash
# Run a standard waypoint mission
python3 simulation.py
# Select: Waypoint Navigation
# Use waypoints: (0,0) → (1,0) → (1,1) → (0,1) → (0,0)

# Check results:
# - Mission completes successfully
# - Final position error < 5cm
# - Final angular error < 3°
# - Plots generate without errors
# - Animation generates without errors
# - CSV data files are generated
```

### Hardware Health Check (If Available)

```bash
# 1. Thruster verification
python3 Thruster_Test/thruster_test.py
# All 8 thrusters should fire cleanly for 1 second each

# 2. Motion capture check
# - Open Motive
# - Place satellite on the floor
# - Verify all markers visible (should see satellite rigid body)
# - Check tracking quality (should be "Excellent" or "Good")

# 3. Simple hardware test
# Run a standard waypoint mission
python3 real.py
# Select: Waypoint Navigation
# Use waypoints: (0,0) → (0.5,0)

# Check results:
# - Mission completes successfully
# - Final position error < 5cm
# - Final angular error < 3°
# - Plots generate without errors
# - Animation generates without errors
# - CSV data files are generated
```

### Establish Performance Baselines

Record these values for future comparison:

- **Test Suite**: Number of tests passing (should be 300+)
- **Simulation MPC solve time**: Average (should be <15ms)
- **Hardware MPC solve time**: Average (should be <15ms)
- **Thruster calibration date**: When last calibrated
- **Tracking quality**: Motive reports "Excellent" with all markers visible

**Save this baseline** - you'll compare against it monthly to detect degradation.

---

## Critical Information

### What You MUST Know

#### 1. Thruster Layout and Coordinate System

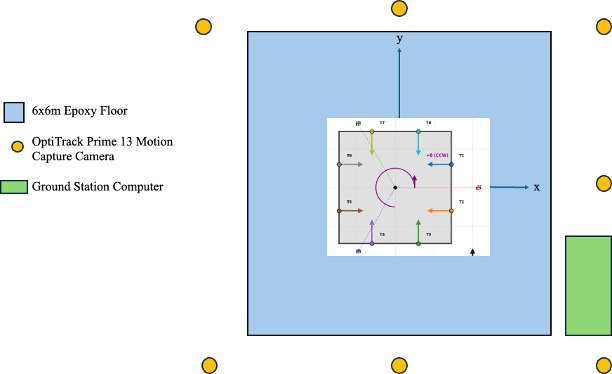
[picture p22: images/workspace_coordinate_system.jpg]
Thruster Layout and Coordinate System


#### 2. Safety

**Kill Switch**:
- Press `Ctrl+C` in terminal
- Close terminal
- Close air supply valves if needed
- Cut OFF power using the switches if needed

#### 3. Simulation vs Real Hardware

**Simulation** uses modeled physics (valve delay, drag, thrust ramp-up).
**Real hardware** will have subtle differences due to:
- Actual valve response time (may vary by thruster)
- Air bearing friction variations
- Environmental air currents
- Sensor noise characteristics

**Always test in simulation first, then on hardware.**

---

## Maintenance Schedule

### Before Every Session

- [ ] Inspect satellite and make sure all components are securely attached
- [ ] Check marker if any marker have fallen off
- [ ] Verify air supply pressure from main regulator (80 PSI ideal)
- [ ] Verify all solenoids work by running "python3 Thruster_Test/thruster_test.py"

### Weekly (if running experiments)

- [ ] Check Motive calibration
  - Open Motive, view 3D
  - If tracking is jittery → recalibrate
- [ ] Inspect air bearing underside for debris
- [ ] Check for unusual vibrations or sounds during operation

### Monthly

- [ ] **Thruster Recalibration** (Recommended!)
- [ ] Run full test suite: `pytest -v`
- [ ] Review log files for errors or warnings
  ```bash
  grep -i "error\|warning" Data/*/simulation.log
  ```
- [ ] Back up any experimental data
- [ ] Document any parameter changes you made

- [ ] **Motive System Recalibration** (Only if cameras have moved)
  - Follow OptiTrack Motive calibration procedure
  - Run wand calibration
  - Only needed if camera positions changed

- [ ] **Air Bearing Maintenance**
  - Clean air bearings, see recommended procedure by manufacturer (New Way Air Bearings)
  - Check for cracks or damage
  - Verify hover stability

---

## Hardware Quirks & Workarounds

### Known Hardware Characteristics

**Thrusters**:
- Individual thrusters may have slightly different response times
- Calibration recommended every 1-2 months depending on usage
- Solenoid valves have limited lifetime
- Check valve response during thruster test before each session

**Air Bearings**:
- Require clean, dust-free environment for optimal performance
- Each bearing may wear at different rates
- Periodic inspection prevents unexpected failures
- Dust or debris can cause catching on the floor

**Motion Capture System**:
- Marker occlusion can occur, ensure clear line of sight from cameras
- Tracking quality degrades if markers get dirty or damaged

**Environmental Factors**:
- Air currents from HVAC can affect trajectories
- Keep doors closed during tests

### Replacement Parts & Supplies

**Keep on hand**:
- Spare solenoid valves (check model in hardware documentation)
- Reflective markers (OptiTrack compatible)
- Extra USB cables for serial connections
- Compressed air cylinders
**Where to order**:
- Solenoid valves: [US Solid Solenoid](https://ussolid.com/products/u-s-solid-electric-solenoid-valve-1-4-12v-dc-solenoid-valve-plastic-nylon-body-normally-closed-nbr-seal-html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)
- Relay: [Soldered Electronics Relay](https://www.digikey.com/en/products/detail/soldered-electronics/333024/21720418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)
- Battery: Any M12 Milwaukee battery
- Air Bearings: [New Way Air Bearings - 40MM Flat Round](https://www.newwayairbearings.com/catalog/product/40mm-flat-round-air-bearings/)
- OptiTrack markers: https://optitrack.com/
- Generic hardware: McMaster-Carr, Amazon
- Air Cylinder: 40 Cubic Feet Compressed Air Zero Grade Cylinder from AWG

### Data Management

**Backup Strategy**:
- Experimental data stored in `Data/` directory
- Back up important results regularly (external drive or cloud)
- Keep CSV files - they're small and contain everything
- Archive mission_summary.txt files for quick reference

**Version Control**:
- If making code changes, use git branches
- Commit configuration changes with clear messages
- Document parameter changes in commit messages
- Consider forking the repo if making major modifications

---

## Common Failures & Solutions

### "Serial port not found"

**Symptom**: `real.py` fails to connect to microcontroller

**Diagnosis**:
```bash
ls /dev/tty*  # macOS/Linux
# Device Manager → Ports (COM & LPT)  # Windows
```

**Solution**:
- Verify USB cable is connected to microcontroller
- Check `/dev/ttyUSB0` (Linux) or `/dev/tty.usbserial-*` (macOS)
- Update `SERIAL_PORT` in config/constants.py if port number changed

### "Motive reports low tracking quality"

**Symptom**: Satellite position jittery or disappears

**Diagnosis**:
- Open Motive → View 3D
- Check if markers visible
- Count how many markers tracked (need ≥3)

**Solution**:
1. Clean markers with soft cloth
2. Verify cameras are focused
3. If cameras moved: recalibrate
   - Follow OptiTrack Motive manual
4. If markers are damaged: replace them

### "GurobiError: Model too large for license"

**Symptom**: Solver refuses to run

**Diagnosis**:
- Check you have academic license (not trial)
- Verify `gurobi.lic` is available locally

**Solution**:
- Get academic license (free): https://www.gurobi.com/academia/
- Place `gurobi.lic` in project root or the standard Gurobi license location
- Keep the license file out of version control
- Restart Python
- Verify: `python3 -c "import gurobipy; print('OK')"`

### Satellite is catching on the floor while hovering

1. Make sure the epoxy floor is clean of dust/hairs/debris
2. Increase air pressure to 70 PSI
3. Air bearing might be clogged, try cleaning it

### Hardware test succeeds but satellite drifts off target

**Symptom**: Mission runs but final position is 20cm off

**Diagnosis**:
- Check if Motive is tracking correctly (compare to visual)
- Check thruster calibration date
- Check for air currents in lab
- Check solver time

**Solution**:
1. Verify Motive accuracy with visual inspection
2. Recalibrate thrusters
3. Close doors to reduce air currents
4. Check MPC parameters aren't too aggressive

### "Timing violation" errors

**Symptom**: Solver takes longer than 50ms (MPC_SOLVER_TIME_LIMIT)

**Diagnosis**:
```python
# Check last few lines of Data/Real_Test/.../real_test_data.csv
# Look for MPC_Computation_Time column
# If consistently > 0.050 (50ms), you have timing issues
```

**Solution** (in order of preference):
1. Close other CPU-intensive applications
2. Reduce `MPC_PREDICTION_HORIZON` in config/mpc_params.py
3. Reduce `MPC_CONTROL_HORIZON`
4. Increase `MPC_SOLVER_TIME_LIMIT`

---

## Important Contacts

### Technical Support (During Your Project)

**Contact Aevar through email**:
- Ask questions about design decisions
- Get help understanding the MPC formulation
- Discuss improvements/extensions
- Email: ofjord99@gmail.com

### For Ongoing Support

**Gurobi Issues**:
- https://support.gurobi.com/
- Free academic support (they're helpful!)

**OptiTrack Motive**:
- https://v21.optitrack.com/support/
- Reference their manual for calibration procedures

**Python/Dependencies**:
- Stack Overflow (for general Python issues)
- Package documentation (numpy, scipy, pyqt5)

### University Resources

**Faculty Advisors**:
- They understand the research goals
- They can approve budget for replacement parts

**Machine Shop**:
- If you need custom parts
- If you need common off the shelf hardware
- They have tools to be used inside the workshop

---

## Documentation You'll Use Most

1. **[HARDWARE_TEST_PROCEDURE.md](HARDWARE_TEST_PROCEDURE.md)**
   - Safety procedures
   - Hardware checks
   - Emergency procedures
   - **Reference this before every hardware run**

2. **[README.md](README.md)**
   - Quick reference for common commands
   - Installation troubleshooting
   - Links to specialized docs

3. **[TROUBLESHOOTING.md](TROUBLESHOOTING.md)**
   - Serial port issues
   - Solver problems
   - Hardware failures

4. **[config/physics.py](config/physics.py)**
   - Thruster positions and forces
   - Satellite mass and inertia
   - Update here when you recalibrate thrusters

5. **[ARCHITECTURE.md](ARCHITECTURE.md)**
   - When you need to understand why something works that way
   - Before modifying core algorithms

6. **[DEVELOPMENT_GUIDE.md](DEVELOPMENT_GUIDE.md)**
   - If you want to add features or fix bugs

---

## Recording Your Own Knowledge

**This is important**: You will learn things the original developer didn't document. Please record them, I made the mistake of not doing this.

### Create a Living Document

Create a file: `NOTES_FROM_[YOUR_NAME].md`

Document:
- Hardware issues you discover
- Parameters that work better than default
- Calibration results and dates
- Lessons learned
- Recommended improvements

**Example**:
```markdown
# Notes from Joe Smith (May 12th 2025)

## Hardware Discoveries
- Thruster 3 has slower response time (valve aging?)
  - Compensated in calibration
  - If fails: replacement solenoid $12, part #XYZ

- Air bearing left side needs daily cleaning
  - Dust accumulation causes vibration
  - Add to morning checklist

## Configuration Tweaks
- Changed MPC_PREDICTION_HORIZON from 15 to 12
  - Reason: Solver timing violations with new simulations
  - Result: Faster (40ms vs 50ms) with minimal loss in optimality

## Calibration Log
- Thruster recalibration: Dec 1, 2025
  - Forces changed ~5-10% from Aevar's original
  - Updated config/physics.py

## Recommended Next Steps
1. Replace solenoid on thruster 3 (backup valve available in cabinet)
2. Implement adaptive solver timeout (Gurobi supports this)
3. Add data logging for long-term performance tracking
```

### What to Document

When something surprises you:
- **"Oh, I need to do X before Y"** → Document it
- **"This parameter seems to work better"** → Document it
- **"This failed, here's the fix"** → Document it
- **"This part will need replacement eventually"** → Document it

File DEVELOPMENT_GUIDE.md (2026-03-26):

# Development Guide

This guide is for developers who want to extend or modify this project for their own research.

**Note**: This is a personal research project, and pull requests are not accepted. If you want to make modifications, fork the repository, work on your own copy, and report bugs back through GitHub issues when relevant.

---

## Table of Contents

- [Quick Start for Development](#quick-start-for-development)
- [Project Structure](#project-structure)
- [Code Style Guidelines](#code-style-guidelines)
- [Working with Data and CSV Logging](#working-with-data-and-csv-logging)
- [Testing Your Changes](#testing-your-changes)
- [Adding New Features](#adding-new-features)
- [Modifying Parameters](#modifying-parameters)
- [Debugging](#debugging)
- [Git Workflow](#git-workflow)
- [Contributing](#contributing)

---

## Quick Start for Development

### Setup

```bash
# Clone YOUR FORK of the repository
# (Fork the repo on GitHub first if you haven't already)
git clone https://github.com/YOUR-USERNAME/mpc-air-bearing-satellite.git
cd mpc-air-bearing-satellite

# Create virtual environment (optional but recommended)
python3 -m venv venv
source venv/bin/activate  # On Windows: venv\Scripts\activate

# Install the package in editable mode
python3 -m pip install -e .

# Install development tools
python3 -m pip install -e ".[dev]"
```

### Verify Everything Works

```bash
# Run tests
pytest -v

# Test simulation
python3 simulation.py

# Check code quality
flake8 .
mypy .
```

---

## Project Structure

For a complete project structure and design overview, see [ARCHITECTURE.md](ARCHITECTURE.md).

### Key Design Principles

1. **Centralized Configuration**: All parameters in `config/` package
   - Never hardcode parameters in other files
   - Import configuration where needed

2. **Modular Architecture**: Each file has a single responsibility
   - `mpc.py`: Optimization only
   - `model.py`: Physics only
   - `simulation.py` / `real.py`: Control loop only

3. **Type Hints**: All functions should have type hints
   - Enables static analysis and IDE support
   - Catch errors before runtime

4. **Docstrings**: Google-style docstrings for all classes and functions
   ```python
   def my_function(x: float, y: float) -> float:
       """Brief description.

       Longer description if needed.

       Args:
           x: Description of x
           y: Description of y

       Returns:
           Description of return value

       Raises:
           ValueError: If x is negative
       """
       return x + y
   ```

---

## Code Style Guidelines

### Python Style (PEP 8)

```bash
# Auto-format code
black .

# Sort imports
isort .

# Check style
flake8 .
```

### Guidelines

- **Line length**: Maximum 100 characters
- **Naming**:
  - Classes: `PascalCase` (e.g., `SatelliteConfig`)
  - Functions: `snake_case` (e.g., `calculate_thrust`)
  - Constants: `UPPER_CASE` (e.g., `CONTROL_DT`)
  - Private: Leading underscore (e.g., `_helper_function`)

- **Imports**: Group in order:
  1. Standard library (`import os`, `import sys`)
  2. Third-party (`import numpy`, `import pandas`)
  3. Local (`from config import SatelliteConfig`)

- **Functions**: Keep < 50 lines when possible
  - Break into smaller functions
  - Each function does one thing

- **Comments**: Explain *why*, not *what*
  ```python
  # Good
  # MPC requires linearization around current state for optimization
  A_lin = compute_linearization(x_current)

  # Avoid
  # Compute linearization
  A_lin = compute_linearization(x_current)
  ```

---

## Working with Data and CSV Logging

### CSV Data Format

Both simulation and real hardware produce identical CSV output with 45 columns per row:

**Detailed Data Log**: `simulation_data.csv` or `real_test_data.csv`
- Contains full control loop data with all state variables, MPC info, and commands
- 45 columns of timestep data
- Organized into categories: Timing & Control, Telemetry, Current State, Target State, Tracking Error, MPC Performance, Command Output, Loop Performance

**Terminal Log**: `simulation_terminal_log.csv` or `real_terminal_log.csv`
- Human-readable status messages
- 8 columns per row

For complete column definitions and descriptions, see [CSV_FORMAT.md](CSV_FORMAT.md).

### Adding Data to Logs

Use the `DataLogger` class in `data_logger.py`:

```python
from data_logger import DataLogger

# Create logger for simulation or real mode
logger = DataLogger(mode="simulation")
logger.set_save_path(Path("./Data/Simulation/test_run"))

# Log each control loop iteration
entry = {
    "Step": step_count,
    "Control_Time": current_time,
    "Current_X": x_position,
    "Current_Y": y_position,
    # ... other 41 columns ...
}
logger.log_entry(entry)

# Save to CSV when done
logger.save_csv_data()
```

**Important**: Always include all expected columns in log entries. Missing columns will appear as empty fields in the CSV.

### Modifying CSV Format

To change CSV format:

1. **Update column definitions**: Edit `_get_simulation_headers()` and `_get_real_headers()` in `data_logger.py`
   - Both must remain identical for consistent comparison between sim and hardware

2. **Update column formatting**: Modify `_format_value()` for precision/format rules

3. **Update documentation**: Reflect changes in [CSV_FORMAT.md](CSV_FORMAT.md)

4. **Update tests**: Modify `tests/test_data_logger.py` to verify new format

5. **Update data collection**: Ensure `simulation.py` and `real.py` populate new columns

---

## Testing Your Changes

### Running Tests

```bash
# Run all tests
pytest

# Run specific test file
pytest tests/test_model.py

# Run specific test function
pytest tests/test_model.py::test_physics_conservation

# Run with verbose output
pytest -v

# Run with coverage report
pytest --cov=. --cov-report=html
# Open htmlcov/index.html to view coverage
```

### Writing Tests

Create a new test file following existing patterns:

```python
# tests/test_myfeature.py
import pytest
from config import SatelliteConfig
from myfeature import my_function

class TestMyFeature:
    """Test suite for my new feature."""

    def test_basic_functionality(self):
        """Test basic case."""
        result = my_function(1, 2)
        assert result == 3

    def test_edge_case(self):
        """Test edge case."""
        with pytest.raises(ValueError):
            my_function(-1, 2)

    @pytest.fixture
    def sample_data(self):
        """Provide sample data for tests."""
        return SatelliteConfig.get_satellite_params()

    def test_with_fixture(self, sample_data):
        """Test using fixture."""
        assert sample_data['mass'] > 0
```

### Testing Workflow

```bash
# 1. Make changes to code
# (Edit simulation.py, model.py, etc.)

# 2. Run tests to catch regressions
pytest

# 3. Test in simulation before hardware
python3 simulation.py

# 4. Hardware test if applicable
python3 real.py
```

---

## Adding New Features

### Example: Adding a New Mission Type

**Goal**: Add "Spiral Navigation" mission

#### Step 1: Define Mission in `mission.py`

```python
def configure_spiral_mission():
    """Configure spiral navigation mission.

    Returns:
        dict: Mission configuration
    """
    mission = {
        'type': 'spiral',
        'start': (0, 0),
        'center': (2, 2),
        'radius_min': 0.5,
        'radius_max': 2.0,
        'revolutions': 2,
        'speed': 0.5,  # m/s target speed
    }
    return mission
```

#### Step 2: Add Logic in `simulation.py` and `real.py`

```python
def update_simulation():
    # ... existing code ...

    if mission_config['type'] == 'spiral':
        target = compute_spiral_target(
            mission_config,
            current_state,
            elapsed_time
        )
        # Rest of control loop with new target
```

#### Step 3: Add Helper Function in `mission.py`

```python
def compute_spiral_target(config, state, time):
    """Compute target position for spiral trajectory.

    Args:
        config: Spiral mission configuration
        state: Current satellite state
        time: Elapsed time in mission

    Returns:
        tuple: (x, y, yaw) target position
    """
    # Implement spiral math here
    pass
```

#### Step 4: Update `visualize.py`

```python
def visualize_spiral_mission(data):
    """Visualize spiral mission results."""
    # Add spiral-specific overlays
    # Plot trajectory over time
    pass
```

#### Step 5: Add Tests in `tests/test_mission.py`

```python
def test_spiral_target_computation():
    """Test spiral target calculation."""
    config = {'center': (2, 2), 'radius_min': 0.5, 'radius_max': 2.0}
    state = {'x': 0, 'y': 0}

    target = compute_spiral_target(config, state, time=1.0)
    assert isinstance(target, tuple)
    assert len(target) == 3  # x, y, yaw
```

#### Step 6: Add Configuration (if needed)

Edit `config/` as needed:

```python
# config/mission_state.py
SPIRAL_SPEED = 0.5  # m/s
SPIRAL_REVOLUTIONS = 2
```

#### Step 7: Update Menu

Edit `simulation.py` to add menu option:

```python
print("3. Spiral Navigation")
# ... handle selection ...
```

#### Step 8: Document

Update [README.md](README.md) mission types section with new mission description.

#### Step 9: Test

```bash
# Run new tests
pytest tests/test_mission.py

# Test in simulation
python3 simulation.py
# Select: 3. Spiral Navigation
```

---

## Modifying Parameters

### Where Parameters Live

All parameters should be in `config/` package:

```
config/
├── physics.py        # Mass, inertia, thruster positions, forces
├── timing.py         # Control rate, simulation step, stabilization times
├── mpc_params.py     # Horizons, cost weights, constraints
├── camera.py         # Camera settings (if used)
├── mission_state.py  # Mission-specific parameters
├── constants.py      # System constants
└── obstacles.py      # Obstacle definitions
```

### Guidelines

1. **Never hardcode values** in other files
   ```python
   # Good
   from config import SatelliteConfig
   mass = SatelliteConfig.get_satellite_params()['mass']

   # Bad
   mass = 12.5  # Hardcoded!
   ```

2. **Group related parameters**
   ```python
   # Good - related parameters together
   MPC_PREDICTION_HORIZON = 15
   MPC_CONTROL_HORIZON = 10
   MPC_SOLVER_TIME_LIMIT = 0.04

   # Bad - scattered around
   ```

3. **Use descriptive names**
   ```python
   # Good
   VELOCITY_THRESHOLD_FOR_DAMPING = 0.03  # m/s

   # Unclear
   V_THRESH = 0.03
   ```

4. **Include units in comments**
   ```python
   MASS = 12.5  # kg
   CONTROL_DT = 0.01  # seconds
   MAX_VELOCITY = 2.0  # m/s
   ```

### Adding New Parameters

```python
# In config/physics.py
NEW_PARAMETER = 1.5  # units

# Then use everywhere:
from config import SatelliteConfig
value = SatelliteConfig.NEW_PARAMETER
```

### Validation

The `SatelliteConfig` class provides parameter validation:

```python
# Validate all configuration parameters
is_valid = SatelliteConfig.validate_parameters()

# This checks:
# - Timing parameters are consistent
# - MPC parameters are reasonable
# - Physics parameters are valid
# - Camera settings are correct
```

You can also add custom validation in your code:

```python
def validate_mission_params(mission_config):
    """Validate mission-specific parameters."""
    params = SatelliteConfig.get_satellite_params()

    assert params['mass'] > 0, "Mass must be positive"
    assert params['inertia'] > 0, "Inertia must be positive"
    assert len(params['thruster_forces']) == 8, "Must have 8 thrusters"

    print("✓ Mission parameters valid")
```

---

## Debugging

### Using Print Statements

```python
import logging

# Configure logging
logging.basicConfig(level=logging.DEBUG)
logger = logging.getLogger(__name__)

# Debug output
logger.debug(f"Current state: x={x}, y={y}, yaw={yaw}")
logger.info("Starting MPC solve")
logger.warning(f"Timing violation: {solve_time} > {time_limit}")
logger.error(f"Failed to solve: {error_msg}")
```

### Interactive Debugging

```python
# Add breakpoint in code
import pdb; pdb.set_trace()

# Or use breakpoint() in Python 3.7+
breakpoint()

# Commands
# n: next line
# s: step into function
# c: continue
# p variable: print variable
# l: list code
# h: help
```

### Inspect Test Behavior

```bash
# Run test with detailed output
pytest tests/test_model.py::test_physics -v -s

# -s: show print/debug output
# -v: verbose
```

### Performance Profiling

```python
import cProfile
import pstats

# Profile a function
cProfile.run('my_function()', 'stats')

# View results
p = pstats.Stats('stats')
p.sort_stats('cumulative').print_stats(10)  # Top 10 functions
```

### Simulation Debugging

```bash
# Enable debug logging
python3 -c "
import logging
logging.basicConfig(level=logging.DEBUG)
exec(open('simulation.py').read())
"
```

---

## Git Workflow

### Working with Your Fork

Since this is a personal research project, **pull requests are not accepted**. If you want to make modifications:

1. **Fork the repository** on GitHub
2. **Clone your fork** locally and make changes
3. **Commit your changes** to your fork
4. **Report bugs** back as issues if you find problems in the original code

### Making Changes in Your Fork

```bash
# 1. Work on your fork
# (You already have cloned and created a branch)
git checkout -b feature/my-new-feature

# 2. Make changes and commit
git add .
git commit -m "Add new feature: describe what and why"

# 3. Push to your fork
git push -u origin feature/my-new-feature

# 4. To report bugs to the original project:
# - Create an issue on GitHub with:
#   - Clear description of the problem
#   - Steps to reproduce
#   - Suggested solution (if you have one)
# - The project maintainer will fix verified bugs when available
```

### Commit Message Guidelines

```
Prefix: brief description

Longer explanation if needed. Describe:
- What changed
- Why it changed
- How to test

Examples:
- "feat: add spiral navigation mission"
- "fix: correct thruster calibration formula"
- "refactor: simplify MPC solver interface"
- "test: add unit tests for physics model"
- "docs: update hardware setup guide"
```

### Before Committing

```bash
# Format code
black .
isort .

# Run tests
pytest

# Check style
flake8 .
mypy .

# Then commit
git add .
git commit -m "Your message"
```

---

## Contributing

### For Your Own Fork

When working on your own fork of this project, follow these best practices:

### Code Quality Checklist

Maintain code quality by ensuring:

- [ ] Code follows PEP 8 style guidelines
- [ ] All functions have docstrings (Google style)
- [ ] Type hints on all functions
- [ ] Tests written for new code
- [ ] All tests pass (`pytest`)
- [ ] No new warnings from `flake8` or `mypy`
- [ ] Documentation updated if needed
- [ ] Commit messages follow guidelines

### Adding Tests

For every new feature or bug fix:

1. Write test that fails (TDD approach)
2. Implement feature/fix
3. Verify test passes
4. Add edge case tests

### Documentation

When modifying your fork:

- Update [README.md](README.md) for user-facing changes
- Update [ARCHITECTURE.md](ARCHITECTURE.md) for design changes
- Update docstrings for code changes
- Update this guide for development process changes

### Reporting Bugs Back

If you discover bugs in the original project:

1. Create an issue on GitHub with:
   - Clear description of the problem
   - Exact steps to reproduce
   - Your environment (OS, Python version, etc.)
   - Error messages or logs if applicable
2. The project maintainer will evaluate and fix verified bugs when available
3. You'll be credited in the issue discussion and commit messages

---

## Common Development Tasks

### Running Simulation with Debug Output

```bash
# In simulation.py, add:
logging.basicConfig(level=logging.DEBUG)

# Then run
python3 simulation.py
```

### Testing New Physics Parameters

```python
# In tests/test_model.py
def test_new_mass():
    from config.physics import MASS
    # Temporarily override for testing
    original_mass = MASS

    # ... test with new value ...

    # Restore
    # (Better: use fixtures)
```

### Comparing Changes

```bash
# See what changed
git diff

# See staged changes
git diff --staged

# Compare branches
git diff main..feature/my-feature
```

### Reverting Changes

```bash
# Undo last commit (keep changes)
git reset --soft HEAD~1

# Undo last commit (discard changes)
git reset --hard HEAD~1

# Undo specific file
git checkout HEAD -- filename.py
```

---

## Troubleshooting Development

### Import Errors

```python
# Problem: "ModuleNotFoundError: No module named 'config'"
# Solution 1: Run from project root
cd /path/to/mpc-air-bearing-satellite
python3 script.py

# Solution 2: Add to path
import sys
sys.path.insert(0, '/path/to/mpc-air-bearing-satellite')
```

### Test Discovery Issues

```bash
# Ensure tests/ has __init__.py
touch tests/__init__.py

# Run with explicit path
pytest tests/

# Run with verbose discovery
pytest --collect-only
```

### Type Checking Issues

```bash
# Install type stubs if needed
pip install types-numpy types-PyYAML

# Check specific file
mypy mpc.py

# Ignore specific line
x = func()  # type: ignore
```

---

## Resources

- **PEP 8**: https://www.python.org/dev/peps/pep-0008/
- **Google Python Style Guide**: https://google.github.io/styleguide/pyguide.html
- **Pytest Documentation**: https://docs.pytest.org/
- **Type Hints**: https://docs.python.org/3/library/typing.html

---

## Related Documentation

This guide complements several other important documents:

- **[README.md](README.md)** - Project overview and quick start
- **[ARCHITECTURE.md](ARCHITECTURE.md)** - System design and component relationships
- **[CSV_FORMAT.md](CSV_FORMAT.md)** - Complete specification of data logging format (45 columns)
- **[SIMULATION_TESTING_GUIDE.md](SIMULATION_TESTING_GUIDE.md)** - Detailed simulation testing procedures
- **[HARDWARE_TEST_PROCEDURE.md](HARDWARE_TEST_PROCEDURE.md)** - Hardware setup and testing procedures

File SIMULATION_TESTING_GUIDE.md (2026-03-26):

# Simulation Testing Guide

Complete guide for running simulation tests without hardware requirements.

**Good for**: Testing control algorithms, mission planning, parameter tuning, and validation before hardware deployment.

---

## Table of Contents

1. [Quick Start](#quick-start)
2. [Installation](#installation)
3. [Running Your First Simulation](#running-your-first-simulation)
4. [Mission Types](#mission-types)
5. [Configuration & Tuning](#configuration--tuning)
6. [Output & Visualization](#output--visualization)
7. [Advanced Testing](#advanced-testing)
8. [Troubleshooting](#troubleshooting)

---

## Quick Start

### Minimal Setup

```bash
# Install dependencies
pip install -r requirements.txt

# Get Gurobi academic license (free for students)
# Keep gurobi.lic local only
# Project root is supported and gitignored

# Run simulation
python3 simulation.py
```

---

## Installation

### 1. Python Dependencies

```bash
pip install -r requirements.txt
```

**Required packages:**
- numpy, scipy, matplotlib
- gurobipy (optimization solver)
- PyQt5 (for visualization)
- opencv-python
- ezdxf, shapely (for DXF missions)

### 2. Gurobi License Setup

Gurobi is **free for academic use**:

1. Register at: https://www.gurobi.com/academia/academic-program-and-licenses/
2. Generate license (use university email)
3. Download `gurobi.lic`
4. Place it in the project root directory or the standard Gurobi license location
5. Keep it out of version control

**Verify installation:**
```bash
python3 -c "import gurobipy as gp; m = gp.Model(); print('Gurobi working!')"
```

### 3. FFmpeg for Animation

**macOS:**
```bash
brew install ffmpeg
```

**Linux:**
```bash
sudo apt install ffmpeg
```

**Windows:**
- Download from https://ffmpeg.org
- Add to PATH or update `FFMPEG_PATH` in `satellite_config.py`

---

## Running Your First Simulation

### Basic Command

```bash
python3 simulation.py
```

### What Happens

1. **Mission Selection** - Interactive prompt asks which mission to run
2. **Configuration** - Set start/target positions, mission parameters
3. **Simulation** - Real-time physics simulation with MPC control
4. **Data Logging** - Saves CSV with all state/control data
5. **Visualization** - Auto-generates MP4 animation and plots

### Example Output

```
Satellite MPC Simulation (Linearized)
=========================================

Select mission mode:
1. Waypoint Mission
2. Shape Following

Enter mode (1-2): 1

--- Configuration ---
Start position: (-1.0, -1.0) m, angle: 90°
Target position: (0.0, 0.0) m, angle: 90°

Running simulation...
Step 100/500 | Position error: 0.15m | MPC: 23ms
Step 200/500 | Position error: 0.08m | MPC: 19ms
Step 300/500 | Position error: 0.03m | MPC: 21ms
Mission complete! Reached target.

Results saved to: Data/Simulation/10-11-2025_14-30-45/
```

---

## Mission Types

The simulation supports 2 primary mission types that test different aspects of satellite control and navigation.

### 1. Waypoint Navigation

Navigate to single or multiple waypoints in sequence with configurable stabilization times.

**Use case:** Path planning, sequential target navigation, inspection missions

**Configuration:**
```python
python3 simulation.py
# Select: 1 (Waypoint Navigation)
# Enter waypoints: (0, 0), (1, 0), (1, 1), (0, 1)
# Specify target angles for each waypoint
# Optional: Configure obstacles for avoidance
```

**Mission behavior:**
- Navigates to each waypoint sequentially
- Stabilizes at each waypoint for configurable time (default: 5s) before proceeding
- Supports obstacle configuration for path planning
- Each waypoint includes position (x, y) and orientation angle
- Final waypoint holds for 10s by default

**What it tests:**
- Waypoint-to-waypoint navigation accuracy
- Waypoint sequencing logic
- Stabilization at each target
- Path planning between points
- Obstacle avoidance (if configured)

**Timing Configuration** (in `config/timing.py`):
- `TARGET_HOLD_TIME`: 5.0 seconds (intermediate waypoints)
- `WAYPOINT_FINAL_STABILIZATION_TIME`: 10.0 seconds (final waypoint)

**Termination:** Completes when all waypoints are visited and satellite stabilizes at final waypoint

---

### 2. Shape Following

Follow a moving target along predefined geometric paths (circles, rectangles, triangles, hexagons, or custom DXF files).

**Use case:** Orbital surveillance, perimeter inspection, formation flying, custom trajectory following

**Configuration:**
```python
python3 simulation.py
# Select: 2 (Shape Following)
# Choose shape: circle, rectangle, triangle, hexagon, or custom DXF
# Shape center: (0, 0) (configurable)
# Rotation angle: 0 degrees (configurable)
# Offset distance: 0.6m (default, satellite path distance from shape)
# Target speed: 0.05 m/s (default)
# Optional: Return position after completing path
```

**Mission behavior:**
- Three execution phases:
  1. **Positioning phase**: Move to closest point on shape and stabilize (5s)
  2. **Tracking phase**: Follow moving target along the entire shape path
  3. **Stabilization phase**: Final hold at completion (15s) or return to starting position
- Target moves along path at configurable speed
- Satellite maintains specified offset distance while following target

**Available Shapes:**
- **Circle** - Smooth circular orbit (36 points, configurable radius)
- **Rectangle** - 0.4m × 0.3m rectangular path
- **Triangle** - Equilateral triangle with 0.4m sides
- **Hexagon** - Regular hexagon with 0.2m radius
- **Custom DXF** - Import any CAD shape from DXF files

**What it tests:**
- Shape trajectory tracking
- Dynamic target following
- Continuous motion control
- Moving reference frame control
- Multi-phase mission execution

**Timing Configuration** (in `config/timing.py`):
- `SHAPE_POSITIONING_STABILIZATION_TIME`: 5.0 seconds (positioning phase)
- `SHAPE_FINAL_STABILIZATION_TIME`: 15.0 seconds (final stabilization)

**Termination:** Completes when shape path is finished and satellite stabilizes for configured time

---

## Configuration & Tuning

### Key Configuration File

**All parameters in**: `satellite_config.py` (or `config/` package)

### Important Parameters

#### Physics
```python
SIMULATION_DT = 0.005        # 5ms - Physics timestep
CONTROL_DT = 0.06           # 60ms - MPC update rate
TOTAL_MASS = 23.09          # kg
MOMENT_OF_INERTIA = 0.312   # kg⋅m²
```

#### MPC Controller
```python
MPC_PREDICTION_HORIZON = 15  # Steps (~0.9s lookahead)
MPC_CONTROL_HORIZON = 12     # Control freedom
MPC_SOLVER_TIME_LIMIT = 0.05 # 50ms max solve time
```

#### Cost Weights
```python
Q_POSITION = 1000.0         # Position tracking
Q_VELOCITY = 1750.0         # Velocity damping
Q_ANGLE = 1000.0            # Angle tracking
Q_ANGULAR_VELOCITY = 1500.0 # Angular damping
R_THRUST = 1.0              # Thrust penalty
```

### Realistic vs Idealized Physics

#### Enable Realistic Physics
```python
# In satellite_config.py
ENABLE_REALISTIC_PHYSICS = True
```

**Includes:**
- Air resistance damping
- Sensor noise
- Thruster delays
- Random disturbances

#### Idealized Physics
```python
ENABLE_REALISTIC_PHYSICS = False
```

**Perfect conditions:**
- No damping
- No noise
- Instant thruster response
- No disturbances

### Tuning Guidelines

**For faster response:**
- ↑ Increase `Q_POSITION`
- ↑ Increase `MPC_PREDICTION_HORIZON`
- ↓ Decrease `R_THRUST`

**For smoother motion:**
- ↑ Increase `Q_VELOCITY`
- ↑ Increase `R_SWITCH` (if thruster switching too frequent)
- ↓ Decrease `MPC_CONTROL_HORIZON`

**For better settling:**
- ↑ Increase `Q_VELOCITY` and `Q_ANGULAR_VELOCITY`
- ↑ Increase `VELOCITY_THRESHOLD`
- ↑ Increase `DAMPING_ZONE`

**Always verify:**
```python
from config import SatelliteConfig
SatelliteConfig.validate_parameters()
```

---

## Output & Visualization

### Automatic Data Saving

After each simulation, data is saved to:
```
Data/Simulation/DD-MM-YYYY_HH-MM-SS/
├── simulation_data.csv       # All state/control data
├── simulation_animation.mp4  # Visual playback
└── simulation_plots.png      # Performance graphs
```

### CSV Data Format

Contains timestamped data:
- Current state (position, velocity, angle)
- Target state
- Errors (position, angle)
- MPC computation time
- Thruster commands
- Timing violations

### Viewing Results

**Auto-generated:**
- Animation created automatically after simulation
- Plots generated automatically

**Manual visualization:**
```bash
# Visualize latest simulation
python3 visualize.py

# Visualize specific run
python3 visualize.py Data/Simulation/10-11-2025_14-30-45/
```

### Data Analysis

```python
import pandas as pd
import numpy as np

# Load data
data = pd.read_csv('Data/Simulation/[timestamp]/simulation_data.csv')

# Calculate metrics
pos_error = np.sqrt(data['Error_X']**2 + data['Error_Y']**2)
avg_error = pos_error.mean()
max_error = pos_error.max()

# MPC performance
avg_solve_time = data['MPC_Computation_Time'].mean() * 1000  # ms
violations = data['Timing_Violation'].sum()

print(f"Average position error: {avg_error:.4f}m")
print(f"Max position error: {max_error:.4f}m")
print(f"Average MPC solve: {avg_solve_time:.1f}ms")
print(f"Timing violations: {violations}")
```

---

## Advanced Testing

### Comparison Testing

Compare simulation vs real hardware tests using the comparison tool:

```bash
python3 comparison.py --real Data/Real_Test/[timestamp]/ --sim Data/Simulation/[timestamp]/
```

Generates side-by-side comparison showing:
- Mission duration
- Thruster activation count
- Position error
- Control effort

### Interactive Testing

Manual thruster control for experimentation:

```bash
python3 testing_environment.py
```

**Controls:**
- **1-8**: Fire individual thrusters
- **Arrow keys**: Directional movement
- **Space**: Stop all thrusters
- **R**: Reset to origin
- **ESC**: Exit

**Use case:** Understanding thruster effects, COM offset testing

### Batch Testing

Run multiple simulations with different parameters:

```python
import subprocess
import numpy as np

# Test different Q_POSITION values
for q_pos in [500, 1000, 2000, 5000]:
    # Update config
    # ... (modify satellite_config.py)

    # Run simulation
    result = subprocess.run(['python3', 'simulation.py'])

    # Analyze results
    # ...
```

### Parameter Sweep

Test range of MPC parameters:

```python
from config import SatelliteConfig
import itertools

horizons = [10, 15, 20]
weights = [500, 1000, 2000]

for pred_h, q_pos in itertools.product(horizons, weights):
    SatelliteConfig.MPC_PREDICTION_HORIZON = pred_h
    SatelliteConfig.Q_POSITION = q_pos

    # Run simulation and log results
    # ...
```

---

## Troubleshooting

### Gurobi License Issues

**Problem:** "Model too large for license"

**Solution:**
- Get academic license (free, larger limits)
- OR reduce `MPC_PREDICTION_HORIZON`

```python
MPC_PREDICTION_HORIZON = 12  # Reduce from 15
MPC_CONTROL_HORIZON = 9      # Reduce from 12
```

### MPC Solver Too Slow

**Problem:** "Solver time limit exceeded" warnings

**Solution:**
```python
# Reduce problem size
MPC_PREDICTION_HORIZON = 12
MPC_CONTROL_HORIZON = 9

# OR increase time limit
MPC_SOLVER_TIME_LIMIT = 0.1  # 100ms
```

### Simulation Unstable

**Problem:** Satellite spinning out of control

**Possible causes:**
- Q_VELOCITY too low (increase damping)
- R_THRUST too high (allow more control)
- MPC_CONTROL_HORIZON too small

**Solution:**
```python
Q_VELOCITY = 2500.0          # More damping
Q_ANGULAR_VELOCITY = 2000.0  # More angular damping
R_THRUST = 0.5               # Less thrust penalty
```

### Can't Reach Target

**Problem:** Simulation never converges

**Possible causes:**
- Target too far
- Thrusters too weak
- Velocity limits too restrictive

**Solution:**
```python
# Check constraints
MAX_VELOCITY = 0.20          # Increase from 0.15
POSITION_THRESHOLD = 0.03    # Relax from 0.02
ANGLE_THRESHOLD = 0.1        # Relax from 0.05
```

### Animation Not Generated

**Problem:** No MP4 file created

**Possible causes:**
- FFmpeg not installed
- Wrong FFmpeg path

**Solution:**
```bash
# Install FFmpeg (see Installation section)

# OR update path in config
FFMPEG_PATH = '/usr/local/bin/ffmpeg'  # macOS
FFMPEG_PATH = '/usr/bin/ffmpeg'        # Linux
FFMPEG_PATH = 'C:/ffmpeg/bin/ffmpeg.exe'  # Windows
```

### Import Errors

**Problem:** `ModuleNotFoundError` or `ImportError`

**Solution:**
```bash
# Reinstall dependencies
pip install --upgrade -r requirements.txt

# Check Python version
python3 --version  # Should be 3.7+

# Use virtual environment
python3 -m venv venv
source venv/bin/activate  # Linux/macOS
venv\Scripts\activate     # Windows
pip install -r requirements.txt
```

---

## Quick Reference

### Common Commands

```bash
# Run simulation
python3 simulation.py

# Visualize data manually
python3 visualize.py

# Interactive virtual environment testing
python3 testing_environment.py

# Comparison test
python3 comparison.py --real Data/Real_Test/<timestamp>/ --sim Data/Simulation/<timestamp>/

# Validate config
python3 -c "from config import SatelliteConfig; SatelliteConfig.validate_parameters()"
```

### Key Files

| Purpose | File | Description |
|---|---|---|
| Run simulation | `simulation.py` | Main simulation script |
| Configure | `satellite_config.py` | All parameters |
| Visualize | `visualize.py` | Generate animations/plots |
| Test manually | `testing_environment.py` | Interactive control |
| Compare | `comparison.py` | Side-by-side comparison |

### Default Parameters

- Simulation timestep: **20ms**
- Control interval: **60ms**
- MPC horizon: **15 steps** (~0.9s)
- Solver limit: **50ms**
- Position threshold: **2cm**
- Angle threshold: **3°**

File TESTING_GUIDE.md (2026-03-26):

# Testing Guide

Comprehensive guide for running, writing, and understanding the test suite.

---

## Table of Contents

- [Quick Start](#quick-start)
- [Test Structure](#test-structure)
- [Running Tests](#running-tests)
- [Understanding Test Results](#understanding-test-results)
- [Writing Tests](#writing-tests)
- [Test Fixtures](#test-fixtures)
- [Integration Testing](#integration-testing)
- [Debugging Tests](#debugging-tests)
- [Test Coverage](#test-coverage)

---

## Quick Start

### Install Testing Tools

```bash
pip install pytest pytest-cov
```

### Run All Tests

```bash
pytest
```

### Run Tests with Coverage Report

```bash
pytest --cov=. --cov-report=html
open htmlcov/index.html  # View report in browser
```

---

## Test Structure

### Directory Layout

```
tests/
├── __init__.py                     # Makes tests a package
├── conftest.py                     # Pytest configuration & fixtures
├── test_config.py                  # Configuration module tests
├── test_model.py                   # Physics model tests
├── test_mpc_controller.py          # MPC solver tests
├── test_mission.py                 # Mission logic tests
├── test_navigation_utils.py        # Navigation helper tests
├── test_integration_basic.py       # Integration: basic setup
├── test_integration_missions.py    # Integration: full missions
└── [other test files]
```

### Test Categories

#### 1. Unit Tests (`test_*.py`)

Test individual modules in isolation.

**Examples**:
- `test_config.py`: Verify configuration validation
- `test_model.py`: Verify physics calculations
- `test_mpc_controller.py`: Verify optimization logic

**Characteristics**:
- Test one function/class at a time
- Use mocks to isolate dependencies
- Fast to run (< 1 second per test)
- Catch bugs early

#### 2. Integration Tests (`test_integration_*.py`)

Test component interactions.

**Examples**:
- `test_integration_basic.py`: System initialization
- `test_integration_missions.py`: Full mission workflows

**Characteristics**:
- Test multiple components together
- Use real (or minimal mocked) dependencies
- Slower than unit tests (1-10 seconds per test)
- Catch integration bugs

#### 3. Test Fixtures (`conftest.py`)

Reusable test data and mocks.

**Examples**:
- `satellite_params`: Standard satellite configuration
- `mock_gurobi_model`: Mocked optimization solver
- `mock_serial_port`: Simulated hardware interface

---

## Running Tests

### Basic Commands

```bash
# Run all tests
pytest

# Run specific test file
pytest tests/test_config.py

# Run specific test class
pytest tests/test_model.py::TestPhysicsModel

# Run specific test function
pytest tests/test_model.py::TestPhysicsModel::test_mass_is_positive

# Run tests matching pattern
pytest -k "physics"  # Run tests with "physics" in name
```

### Verbose Output

```bash
# Show test names and results
pytest -v

# Show print statements
pytest -s

# Show both
pytest -vs
```

### Filtering Tests

```bash
# Run only fast tests (skip slow)
pytest -m "not slow"

# Run only unit tests
pytest tests/test_*.py

# Run only integration tests
pytest tests/test_integration_*.py

# Run tests by keyword
pytest -k "mpc"  # Run tests with "mpc" in name
pytest -k "not slow"  # Skip slow tests
```

### Output Formats

```bash
# Minimal output
pytest -q

# Detailed output with line numbers
pytest -v --tb=long

# Stop at first failure
pytest -x

# Stop after N failures
pytest --maxfail=3

# Show local variables in tracebacks
pytest -l
```

---

## Understanding Test Results

### Test Output

```
tests/test_config.py::test_mass_is_positive PASSED          [10%]
tests/test_config.py::test_inertia_is_positive PASSED       [20%]
tests/test_model.py::TestPhysicsModel::test_thrust PASSED   [30%]
...

====== 47 passed in 1.23s ======
```

### Interpreting Symbols

- ✓ `PASSED`: Test succeeded
- ✗ `FAILED`: Test failed (assertion or exception)
- ⊘ `SKIPPED`: Test was skipped (e.g., missing dependency)
- ⚠ `XFAIL`: Expected failure (test expected to fail)
- ⊙ `XPASS`: Unexpected pass (test expected to fail but passed)
- `ERROR`: Setup or teardown failed

### Common Failures

#### AssertionError

```
AssertionError: assert 3.14159 == 3.14159265
```
**Cause**: Assertion failed. Check the condition.

#### TypeError

```
TypeError: unsupported operand type(s) for /: 'str' and 'float'
```
**Cause**: Wrong type passed to function. Check inputs.

#### ModuleNotFoundError

```
ModuleNotFoundError: No module named 'config'
```
**Cause**: Missing dependency or import path. Check installation.

#### TimeoutError (from pytest.timeout)

```
TimeoutError: Test took too long
```
**Cause**: Test hangs (infinite loop or waiting for external resource).

---

## Writing Tests

### Basic Test Structure

```python
# tests/test_example.py
import pytest
from config import SatelliteConfig
from model import compute_acceleration

class TestPhysics:
    """Test suite for physics calculations."""

    def test_acceleration_is_positive_for_positive_force(self):
        """Test that positive force produces positive acceleration."""
        mass = 10.0
        force = 5.0
        acceleration = force / mass

        assert acceleration > 0
        assert acceleration == pytest.approx(0.5)

    def test_acceleration_raises_for_zero_mass(self):
        """Test that zero mass raises error."""
        with pytest.raises(ZeroDivisionError):
            acceleration = 5.0 / 0.0
```

### Naming Conventions

```python
# Good test names describe what is tested
def test_mass_is_positive():
    """Test that satellite mass is positive."""
    pass

def test_thruster_force_increases_with_pressure():
    """Test that higher pressure produces more force."""
    pass

# Avoid unclear names
def test_physics():  # Too vague
    pass

def test_1():  # No meaning
    pass
```

### Assertion Examples

```python
# Equality
assert result == 5

# Approximate equality (for floats)
assert result == pytest.approx(3.14159, abs=1e-5)

# Comparisons
assert value > 0
assert value >= threshold

# Membership
assert element in collection
assert 'key' in dictionary

# Identity
assert obj is None
assert obj is not None

# Type checking
assert isinstance(obj, MyClass)

# Exception handling
with pytest.raises(ValueError):
    function_that_should_raise()

with pytest.raises(ValueError, match="error message"):
    function_that_raises_with_message()
```

### Test Phases

```python
def test_complete_workflow():
    """Example test with all phases."""
    # Arrange: Set up test data
    x = 1.0
    y = 2.0

    # Act: Execute code being tested
    result = add(x, y)

    # Assert: Verify result
    assert result == 3.0

    # Cleanup: Happens automatically (or use fixtures)
```

---

## Test Fixtures

### Built-in Fixtures

```python
# Temporary directory
def test_with_temp_dir(tmp_path):
    file = tmp_path / "test.txt"
    file.write_text("hello")
    assert file.read_text() == "hello"

# Monkeypatch (mock objects)
def test_with_monkeypatch(monkeypatch):
    import os
    monkeypatch.setenv("MY_VAR", "test_value")
    assert os.environ["MY_VAR"] == "test_value"
```

### Custom Fixtures

```python
# conftest.py
import pytest
from config import SatelliteConfig

@pytest.fixture
def satellite_params():
    """Provide standard satellite parameters."""
    return SatelliteConfig.get_satellite_params()

@pytest.fixture
def mpc_config():
    """Provide standard MPC configuration."""
    return SatelliteConfig.get_mpc_params()

# Use in test
def test_with_fixture(satellite_params):
    assert satellite_params['mass'] > 0
```

### Fixture Scopes

```python
# Function scope: New fixture for each test
@pytest.fixture(scope="function")
def new_each_time():
    return create_resource()

# Class scope: One fixture per test class
@pytest.fixture(scope="class")
def shared_in_class():
    return create_expensive_resource()

# Module scope: One fixture per module
@pytest.fixture(scope="module")
def expensive_setup():
    return very_expensive_resource()

# Session scope: One fixture for entire test run
@pytest.fixture(scope="session")
def database_connection():
    return setup_database()
```

### Fixture Cleanup

```python
@pytest.fixture
def resource_with_cleanup():
    """Fixture that cleans up after use."""
    resource = create_resource()
    yield resource  # Provide to test
    cleanup_resource(resource)  # Clean up after

def test_with_cleanup(resource_with_cleanup):
    # Use resource
    assert resource_with_cleanup is not None
    # Cleanup happens automatically after test
```

---

## Integration Testing

### Testing Full Mission Workflow

```python
# tests/test_integration_missions.py
import pytest
from simulation import run_simulation_step
from mission import configure_waypoint_mission
from config import SatelliteConfig

def test_waypoint_navigation_completes():
    """Test complete waypoint navigation mission."""
    # Configure mission
    mission = configure_waypoint_mission(
        waypoints=[(0, 0), (1, 0), (1, 1)]
    )

    # Initialize state
    state = {
        'x': 0, 'y': 0, 'yaw': 0,
        'vx': 0, 'vy': 0, 'angular_vel': 0
    }

    # Run simulation
    completed = False
    for step in range(10000):  # Max steps
        state = run_simulation_step(state, mission)

        if state['mission_complete']:
            completed = True
            break

    assert completed, "Mission did not complete"
    assert state['x'] == pytest.approx(1.0, abs=0.1)
    assert state['y'] == pytest.approx(1.0, abs=0.1)
```

### Testing Component Integration

```python
def test_mpc_produces_valid_commands(satellite_params, mpc_config):
    """Test that MPC solver produces valid thruster commands."""
    from mpc import MPCController

    controller = MPCController(satellite_params, mpc_config)

    # Set a target
    current_state = [0, 0, 0, 0, 0, 0]  # x, y, yaw, vx, vy, w
    target_state = [1, 1, 0, 0, 0, 0]   # Go to (1, 1)

    # Solve
    commands = controller.solve(current_state, target_state)

    # Verify commands are valid
    assert len(commands) == 8  # 8 thrusters
    for cmd in commands:
        assert cmd in [0, 1]  # Binary command
```

---

## Debugging Tests

### Using print() and logging

```python
def test_with_debug_output():
    """Test with debug output."""
    x = compute_something()
    print(f"Debug: x = {x}")  # Use -s flag to see
    assert x > 0
```

Run with:
```bash
pytest -s test_example.py
```

### Using pytest.set_trace()

```python
def test_with_breakpoint():
    """Test with interactive debugger."""
    x = 5
    pytest.set_trace()  # Debugger pauses here
    y = x * 2
    assert y == 10
```

Run with:
```bash
pytest --pdb test_example.py
```

### Using pdb

```python
def test_with_pdb():
    """Test with pdb debugger."""
    import pdb
    x = 5
    pdb.set_trace()  # Debugger pauses here
    y = x * 2
    assert y == 10
```

### Pytest Options for Debugging

```bash
# Stop at first failure and drop into debugger
pytest --pdb

# Show local variables on failure
pytest -l

# Show print statements
pytest -s

# Verbose output
pytest -v

# Last failed tests
pytest --lf

# Failed tests first
pytest --ff
```

---

## Test Coverage

### Generate Coverage Report

```bash
# Generate coverage
pytest --cov=. --cov-report=html

# View report
open htmlcov/index.html
```

### Understanding Coverage

```
Name                  Stmts   Miss  Cover   Missing
--------------------------------------------------
config/__init__.py       45      2    96%   12-13
model.py               120     10    92%   45-48, 67
mpc.py                 200      5    98%   150-151
simulation.py          250     20    92%   100-120
--------------------------------------------------
TOTAL                  615     37    94%
```

- **Stmts**: Total statements
- **Miss**: Statements not executed
- **Cover**: Percentage covered
- **Missing**: Line numbers not covered

### Coverage Goals

- **Overall**: Aim for > 80% coverage
- **Critical**: MPC, physics model > 95%
- **Utilities**: Test helpers > 70%

### Excluding Code from Coverage

```python
# Exclude function from coverage
def rarely_used_function():  # pragma: no cover
    pass

# Exclude block
if debug_mode:  # pragma: no cover
    print("Debug info")
```

### Coverage Commands

```bash
# Minimum coverage threshold
pytest --cov=. --cov-fail-under=80

# Coverage per module
pytest --cov=. --cov-report=term-missing

# XML report (for CI/CD)
pytest --cov=. --cov-report=xml
```

---

## Common Testing Patterns

### Testing with Mocks

```python
from unittest.mock import Mock, patch

def test_with_mock():
    """Test using mocked dependency."""
    # Create mock
    mock_solver = Mock()
    mock_solver.solve.return_value = [1, 0, 1, 0, 0, 0, 1, 0]

    # Use mock
    result = mock_solver.solve([0, 0, 0, 0, 0, 0])

    # Verify calls
    mock_solver.solve.assert_called_once()
    assert result[0] == 1
```

### Parametrized Tests

```python
import pytest

@pytest.mark.parametrize("mass,expected_inertia", [
    (10.0, 0.45),
    (12.5, 0.56),
    (15.0, 0.67),
])
def test_inertia_scales_with_mass(mass, expected_inertia):
    """Test that inertia scales correctly with mass."""
    from config import SatelliteConfig
    # Mock calculation
    calculated = mass * 0.045  # Simple scaling
    assert calculated == pytest.approx(expected_inertia, rel=0.01)
```

### Skipping Tests

```python
@pytest.mark.skip(reason="Not implemented yet")
def test_future_feature():
    pass

@pytest.mark.skipif(True, reason="Disabled for now")
def test_disabled_feature():
    pass

# Conditional skip
import sys
@pytest.mark.skipif(sys.platform == "win32", reason="Unix only")
def test_unix_feature():
    pass
```

### Expected Failures

```python
@pytest.mark.xfail(reason="Known bug in library")
def test_known_issue():
    assert False  # Expected to fail

@pytest.mark.xfail(strict=True)
def test_should_fail_strictly():
    """Test that must fail."""
    assert False
```

---

## Test Examples

### Configuration Tests

```python
# tests/test_config.py
def test_satellite_params_valid():
    """Verify satellite parameters are physically reasonable."""
    from config import SatelliteConfig
    params = SatelliteConfig.get_satellite_params()

    assert params['mass'] > 0
    assert params['inertia'] > 0
    assert len(params['thruster_forces']) == 8
    assert all(f > 0 for f in params['thruster_forces'])
```

### Physics Model Tests

```python
# tests/test_model.py
def test_force_produces_acceleration():
    """Test Newton's second law: F = ma."""
    from model import compute_acceleration

    mass = 10.0
    force = 25.0
    expected = force / mass  # 2.5 m/s^2

    actual = compute_acceleration(force, mass)
    assert actual == pytest.approx(expected)
```

### MPC Tests

```python
# tests/test_mpc_controller.py
def test_mpc_converges_to_target():
    """Test that MPC moves toward target."""
    from mpc import MPCController

    controller = MPCController(satellite_params, mpc_config)

    current = [0.0, 0.0, 0.0, 0.0, 0.0, 0.0]  # At origin
    target = [1.0, 1.0, 0.0, 0.0, 0.0, 0.0]   # Move to (1, 1)

    commands = controller.solve(current, target)

    # Should produce valid commands
    assert len(commands) == 8
    assert all(cmd in [0, 1] for cmd in commands)
```

---

## Continuous Integration

### GitHub Actions Example

```yaml
# Example CI workflow for your fork
name: Tests

on: [push, pull_request]

jobs:
  test:
    runs-on: ubuntu-latest
    strategy:
      matrix:
        python-version: [3.9, 3.10, 3.11, 3.12]

    steps:
    - uses: actions/checkout@v2
    - name: Set up Python
      uses: actions/setup-python@v2
      with:
        python-version: ${{ matrix.python-version }}

    - name: Install dependencies
      run: |
        pip install -r requirements.txt
        pip install pytest pytest-cov

    - name: Run tests
      run: pytest --cov=. --cov-report=xml

    - name: Upload coverage
      uses: codecov/codecov-action@v2
```

---

## Troubleshooting Tests

### Tests Won't Run

```bash
# Issue: ModuleNotFoundError
# Solution: Run from project root
cd /path/to/mpc-air-bearing-satellite
pytest

# Issue: Can't find conftest
# Solution: Ensure tests/ has __init__.py
touch tests/__init__.py
```

### Test Takes Forever

```bash
# Issue: Test hangs
# Solution: Set timeout
pytest --timeout=5

# Check for infinite loops or blocking I/O
pytest -s --tb=short  # See where it hangs
```

### Flaky Tests

```python
# Issue: Test passes sometimes, fails sometimes
# Solution: Check for timing/randomness issues

# Retry decorator
@pytest.mark.flaky(reruns=3)
def test_flaky_behavior():
    # Test that might fail randomly
    pass

# Control randomness
import random
def test_with_seed():
    random.seed(42)  # Reproducible
```

---

## Resources

- **Pytest Documentation**: https://docs.pytest.org/
- **Pytest Fixtures**: https://docs.pytest.org/how-to/fixtures.html
- **Testing Best Practices**: https://docs.pytest.org/goodpractices.html

---

**See also**: [DEVELOPMENT_GUIDE.md](DEVELOPMENT_GUIDE.md), [README.md](README.md)

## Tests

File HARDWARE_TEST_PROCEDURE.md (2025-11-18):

# Hardware Test Procedure

Complete step-by-step procedure for running hardware tests with the satellite testbed.

**SAFETY FIRST**: Always follow proper safety protocols when working with pressurized air systems and moving hardware.

---

## Table of Contents

1. [Pre-Flight Checklist](#pre-flight-checklist)
2. [Thruster Calibration](#thruster-calibration)
3. [Battery Setup](#battery-setup)
4. [Floor Preparation](#floor-preparation)
5. [Air Cylinder Verification](#air-cylinder-verification)
6. [Satellite Balancing](#satellite-balancing)
7. [Air System Setup](#air-system-setup)
8. [ESP32 Gateway Connection](#esp32-gateway-connection)
9. [OptiTrack Setup](#optitrack-setup)
10. [Motive Data Server](#motive-data-server)
11. [Camera Configuration](#camera-configuration)
12. [Final Checks and Launch](#final-checks-and-launch)
13. [Troubleshooting](#troubleshooting)

---

## Pre-Flight Checklist

Before starting, ensure you have:

- [ ] Both 12V batteries fully charged
- [ ] Battery adapter/mount ready
- [ ] ESP32 gateway and USB cable
- [ ] Computer with all software/packages installed
- [ ] OptiTrack cameras powered
- [ ] Satellite platform accessible
- [ ] Three scales for balancing
- [ ] Soft cloths for protecting air bearings
- [ ] Sweep for floor
- [ ] Air cylinder with sufficient pressure (at least 500 psi)

---

## Thruster Calibration

Thruster calibration measures the **thrust output** of each thruster and generates calibration values for the MPC controller. This is essential for accurate attitude control.

**For detailed calibration procedures**, see [THRUSTER_CALIBRATION.md](THRUSTER_CALIBRATION.md).

---

## Battery Setup

### 3.1 Battery Installation

1. **Verify charge level** on both 12V batteries:
   - Connect batteries to charger if needed
   - Ensure full charge before installation

2. **Install batteries**:
   - Turn OFF both power switches
   - Plug both batteries into the battery adapters
   - Ensure secure connections
   - Turn ON both power switches

---

## Floor Preparation

### 4.1 Clean the Epoxy Floor

**Critical for proper operation!** Dust and debris can cause:
- Unwanted friction affecting motion
- External torques causing rotation
- Damage to air bearings

**Cleaning procedure:**

1. **First sweep**:
   - Use a clean Swiffer cloth
   - Sweep entire 6×6 meter test area
   - Pay attention to corners and edges

2. **Second sweep**:
   - Sweep again in perpendicular direction
   - Ensures all debris and dust is removed

3. **Visual inspection**:
   - Check for any remaining dust, hair, or particles
   - The floor should be spotless

> **Important**: Clean the floor **immediately before** placing the satellite. Don't clean hours in advance.

---

## Air Cylinder Verification

### 5.1 Verify Air Cylinder Pressure

Before proceeding with any tests, verify that your air cylinder has sufficient pressure:

1. **Screw the main regulator** onto the air cylinder
   - Turn the regulator fully to the left (so no air gets out)

2. **Open the valve** on the air cylinder
   - Check the pressure gauge

3. **Verify pressure level**:
   - Meter should read **500 PSI or higher**
   - If pressure is low, replace air cylinder

---

## Satellite Balancing

### 6.1 Equipment Setup

1. **Prepare three scales**:
   - Place scales on the epoxy floor in the corner off negative x negative y
   - Zero each scale

2. **Protect air bearings**:
   - Place a soft cloth on each scale
   - **Never** place air bearings directly on hard surfaces
   - This prevents scratches and damage

### 6.2 Initial Placement

   **Carefully place satellite** on the three scales
   - One air bearing per scale
   - Ensure satellite is level
   - Place air cylinder in the mount

### 6.3 Balancing Procedure

**Goal**: Get all three air bearings within **±50 grams** of each other.

#### Method 1: Rotate Air Cylinder

1. **Loosen air cylinder mount**

2. **Rotate cylinder slowly**:
   - Rotate in small increments
   - Check weights after each adjustment
   - Continue until balanced

3. **Tighten mount** when balanced

#### Method 2: Adjust Balance Weights

For fine-tuning:

1. **Locate small weights** mounted on the satellite body

2. **Move weights** to redistribute mass:

3. **Re-measure** until balanced

#### Method 3: Adjust Air Bearing Positions (Least recommended)

If Method 1 and 2 doesn't achieve balance:

1. **Loosen air bearing nuts**
   - Air bearings can slide along grooves in the base

2. **Move heavy-side bearing** slightly outward
   - OR move light-side bearing slightly inward

3. **Re-measure and repeat** until balanced

### 6.4 Final Balance Check

- [ ] All three scales within ±50g of each other
- [ ] Weights recorded for reference
- [ ] All mounts and screws tightened
- [ ] Update weights in code

---

## Air System Setup

### 7.1 Pressure Settings

| System | Pressure | Purpose |
|---|---|---|
| Main Regulator | 80 PSI | Primary air supply |
| Air Bearings | 60 PSI | Creates hover cushion |
| Thrusters | 40 PSI | Thruster actuation force |

**Important**: If you change thruster pressure from 40 PSI, you **must** recalibrate all 8 thrusters and update thrust values in the code.

### 7.2 Air System Startup Sequence

1. **Open main air cylinder valve** (fully open)

2. **Set main regulator** to 80 PSI

3. **Set air bearing regulator** to 60 PSI
   - This is the "float" pressure
   - Too low = satellite won't hover
   - Too high = unstable hover (max 80 psi, higher values will damage the air bearings)

4. **Make sure thruster regulator is set to** to 40 PSI
   - Standard operating pressure
   - Calibrated thrust values are for 40 PSI
   - If adjusted new calibration is needed

5. **Open air bearing valve**

6. **Open thruster valve**

### 7.3 Pressure Verification

- [ ] Main regulator: 80 PSI ±2 PSI
- [ ] Air bearing regulator: 60 PSI ±2 PSI
- [ ] Thruster regulator: 40 PSI ±2 PSI
- [ ] No air leaks detected (audible check)
- [ ] All valves in correct positions

---

## ESP32 Gateway Connection

### 8.1 Connect Gateway

1. **Plug in ESP32 gateway** to computer via USB

2. **Identify the port**:

   **On macOS/Linux:**
   ```bash
   ls /dev/tty.*
   # or
   ls /dev/ttyUSB*
   ```

   **On Windows:**
   - Open Device Manager → Ports (COM & LPT)
   - Note the COM port number (e.g., COM20)

### 8.2 Update Serial Port Configuration

Edit `config/constants.py`:

```python
# Line 55
SERIAL_PORT = '/dev/tty.usbserial-XXXXX'  # macOS
# or
SERIAL_PORT = '/dev/ttyUSB0'              # Linux
# or
SERIAL_PORT = 'COM20'                      # Windows
```

> **File location**: `/config/constants.py` (line 55)

---

## OptiTrack Setup

### 9.1 Power On Cameras

1. **Turn on all OptiTrack cameras**
   - Wait for cameras to fully boot (LED indicators stable)
   - Typically takes 30-60 seconds

### 9.2 Launch Motive Software

1. **Open Motive** on the computer

2. **Load your calibration**:
   - File → Open → Select your calibrated project (create one if not done already)
   - Verify all cameras are active

3. **Verify tracking**:
   - Place a **dummy marker set** on the floor
   - Confirm Motive displays the rigid body
   - Check position values are stable and reasonable

### 9.3 Tracking Verification Checklist

- [ ] All cameras show as active in Motive
- [ ] Dummy rigid body appears in 3D view
- [ ] Position values are stable (not jumping)
- [ ] Frame rate shows ~240 fps
- [ ] No tracking errors or warnings

---

## Motive Data Server

### 10.1 Start Data Streaming

The Motive data server bridges Motive tracking data to your Python control system.

**Start the server:**

```bash
python3 Motive/motive_data_server.py
```

> **File location**: `Motive/motive_data_server.py`

### 10.2 Verify Data Transfer

You should see output similar to:
```
[INFO] Connected to Motive
[INFO] Streaming rigid body data...
[INFO] Rigid Body 0: x=0.123, y=0.456, z=0.789
```

### 10.3 Troubleshooting Data Stream

If no data appears:
1. Check Motive is in "Streaming" mode
2. Verify network settings (usually localhost)
3. Ensure rigid body is defined in Motive
4. Check firewall settings

---

## Camera Configuration

### 11.1 Ground Station Hotspot

1. **Enable hotspot** on the ground station computer (make sure to name you hotspot "MittNet" and set the password to "Satellite123" or reflash the esp32s3 sense cameras with new name and password)
   - Hotspot name: MittNet
   - Password: Satellite123

2. **Wait for cameras to connect** (30-60 seconds)
   - The 4 ESP32s3 sense cameras will auto-connect

### 11.2 Find Camera IP Addresses

**Check connected devices:**

- **On macOS/Linux**: Check System Preferences → Network → Hotspot
- **On Windows**: Settings → Network → Mobile hotspot → Connected devices
- **Or use**: `arp -a` command to list connected devices

You should see 4 devices with IPs like: `192.168.137.XX`

### 11.3 Update Camera URLs

Edit `config/camera.py`:

```python
# Lines 79-84
CAMERA_URLS = {
    "Front": "http://192.168.137.XX:81/stream",  # Update XX with actual IP
    "Right": "http://192.168.137.YY:81/stream",  # Update YY with actual IP
    "Back":  "http://192.168.137.ZZ:81/stream",  # Update ZZ with actual IP
    "Left":  "http://192.168.137.WW:81/stream",  # Update WW with actual IP
}
```

> **File location**: `config/camera.py` (lines 79-84)

### 11.4 Test Camera Streams

You can test individual camera URLs in a web browser:
```
http://192.168.137.XX:81/stream
```

Each stream should show live video from the camera.

---

## Final Checks and Launch

### 12.1 Pre-Launch Checklist

Go through the complete system:

**Power:**
- [ ] Both battery switches ON
- [ ] ESP32 gateway connected and responding
- [ ] All LEDs showing expected states (OFF when inactive, ON when active)

**Tracking:**
- [ ] Motive showing satellite position
- [ ] motive_data_server.py running
- [ ] Position data streaming correctly

**Cameras:**
- [ ] All 4 cameras connected to hotspot
- [ ] Camera streams accessible
- [ ] Camera URLs updated in config

**Air System:**
- [ ] Air bearings pressurized (60 PSI)
- [ ] Thrusters pressurized (40 PSI)
- [ ] Main regulator at 80 PSI
- [ ] No air leaks

**Software:**
- [ ] Serial port configured correctly
- [ ] Thrusters tested and verified
- [ ] Mission parameters set
- [ ] Emergency stop procedure reviewed

### 12.2 Place Satellite on Floor

1. **Carefully lift satellite** from scales
   - Support from multiple points
   - Keep level during transfer

2. **Place on cleaned floor**
   - Verify hover is stable
   - Satellite should float smoothly

3. **Verify hover quality**:
   - Satellite should spin freely with gentle push
   - No scraping sounds

### 12.3 Launch Test Mission

**Start the control system:**

```bash
python3 real.py
```

> **File location**: `real.py`

**What happens:**
1. System initializes connections
2. Cameras start streaming
3. Position tracking begins
4. Control loop starts
5. Mission executes

### 12.4 Monitor During Test

**Watch for:**
- Position tracking in Motive
- Camera feeds showing motion
- Terminal output for errors
- Satellite staying within bounds
- Smooth, controlled motion

**Emergency Stop:**
- Press `Ctrl+C` in terminal
- Close air supply valve if needed
- Cut OFF power using the switches if needed

---

## Troubleshooting

### Satellite Won't Hover

**Possible causes:**
- Air bearing pressure too low (increase to 60 PSI)
- Air bearings clogged (inspect and clean)
- Main valve not fully open
- Leak in air bearing lines

### Thrusters Not Firing

**Possible causes:**
- Battery power OFF
- Wrong serial port configured
- Thruster solenoid failure (test individually)
- Loose wires

### Tracking Lost

**Possible causes:**
- Markers obscured from cameras
- Lighting too bright/dim
- Rigid body lost in Motive
- motive_data_server.py crashed (restart it)

### Unstable Motion

**Possible causes:**
- Floor not clean (re-sweep)
- Satellite not balanced (re-balance on scales)
- Air bearing pressure inconsistent
- External air currents (close doors)

### Camera Streams Not Working

**Possible causes:**
- Cameras not connected to hotspot (check hotspot)
- Wrong IP addresses in config (verify IPs)
- Camera offline (power cycle camera)

### Unexpected Rotation

**Possible causes:**
- Satellite not balanced (check ±50g tolerance)
- Debris on floor (clean floor again)
- COM offset not calibrated correctly
- Thruster forces not calibrated

---

## Emergency Procedures

### Emergency Stop

1. **Press Ctrl+C** in control terminal
2. **Close thruster valve** immediately
3. **Close air bearing valve** if needed
4. **Turn OFF battery switches**

### Air System Failure

1. **Close main valve** on air cylinder
2. **Release pressure** from all regulators
3. **Turn OFF battery power**
4. **Do not attempt to restart** until issue resolved

### Collision Risk

1. **Emergency stop** (Ctrl+C)
2. **Manually stop satellite**
3. **Review mission parameters** before restarting

---

## Post-Test Shutdown

### Proper Shutdown Sequence

1. **Stop control program** (Ctrl+C)

2. **Close thruster valve**

3. **Close main air cylinder valve**

4. **Leave air bearing valve open to depressurize the system**

5. **Turn OFF battery switches**

6. **Stop motive_data_server.py** (Ctrl+C)

7. **Close Motive software**

8. **Disconnect ESP32 gateway**

9. **Turn OFF hotspot**

### Data Collection

After each test, collect:
- [ ] CSV data files from `Data/Real_Test/`
- [ ] Camera recordings (if enabled)
- [ ] Motive tracking data (if saved)
- [ ] Any error logs

---

## Quick Reference

### Key File Locations

| Configuration | File | Line |
|---|---|---|
| Serial Port | `config/constants.py` | 55 |
| Camera URLs | `config/camera.py` | 79-84 |
| Thruster Calibration | `Thruster_Test/thrust_calibration.py` | - |
| Motive Server | `Motive/motive_data_server.py` | - |
| Hardware Control | `real.py` | - |

### Standard Operating Pressures

- Main: **80 PSI**
- Air Bearings: **60 PSI**
- Thrusters: **40 PSI**

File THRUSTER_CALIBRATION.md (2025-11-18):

# Thruster Calibration Guide

Complete procedure for calibrating the 8 satellite thrusters and generating thrust values for the MPC controller.

**CRITICAL REQUIREMENTS**:
- **The satellite must be powered ON** with both 12V batteries installed and battery switches ON
- **ESP32 gateway must be connected to a computer** via USB for solenoid command communication
- **ESP32 for the load cell reading must be connected to a computer** to record data collected
- **Without these connections, thrust_calibration.py cannot send commands to open thrusters and no data is saved**

**IMPORTANT**: Thruster calibration must be performed before any mission operations to ensure accurate attitude control.

---

## Table of Contents

1. [Overview](#overview)
2. [Equipment Required](#equipment-required)
3. [Pre-Calibration Setup](#pre-calibration-setup)
4. [Running Calibration](#running-calibration)
5. [Analyzing Results](#analyzing-results)
6. [Updating Configuration](#updating-configuration)
7. [Troubleshooting](#troubleshooting)

---

## Overview

### What is Thruster Calibration?

Thruster calibration measures the **thrust output** of each of the 8 satellite thrusters. This data is essential for:

- **Accurate force control**: MPC controller must know exact thrust values
- **Attitude predictability**: Consistent thrust enables precise rotational control
- **Mission success**: Without calibration, control commands produce unpredictable results

### How It Works

The calibration system uses a **precision load cell** to measure force while each thruster fires sequentially. For each thruster:

1. **Baseline stabilization** (3 seconds) - Establishes zero reference
2. **Pulse sequence** (15 pulses) - Each pulse:
   - Pre-pulse phase (0.5s) - Baseline
   - Firing phase (10s) - Thruster active, force measured
   - Post-pulse phase (1.0s) - Force decay
   - Rest period (5s) - Cool down between pulses
3. **Data analysis** - Extract steady-state thrust from measurements
4. **Statistical summary** - Median thrust value recommended

### Key Operating Parameters

| Parameter | Value | Notes |
|---|---|---|
| Test duration per thruster | 10 seconds | Fixed firing duration per pulse |
| Pulses per thruster | 15 | Ensures statistical confidence |
| Pause between pulses | 5 seconds | Allows pressure stabilization |
| Air pressure (standard) | 40 PSI | Must match mission operating pressure |
| Load cell sampling rate | ~50 Hz | 20ms interval between readings |

---

## Equipment Required

### Hardware

- [ ] **Load cell system** (HX711-based with Xiao ESP32-S3 microcontroller)
  - Mounted on thrust bench
  - Calibrated and zeroed
- [ ] **ESP32 gateway** (for sending solenoid commands to thrusters)
  - Mounted on satellite
  - Powered by 12V batteries
- [ ] **USB cables** (2 total)
  - One USB cable for ESP32 gateway (solenoid commands)
  - One USB cable for Xiao ESP32-S3 (load cell data)
- [ ] **Satellite with 8 thrusters** mounted and connected
- [ ] **Two 12V batteries** (fully charged)
  - Required for thruster command communication
  - Battery adapters/mounts
- [ ] **Air supply** connected to the thruster regulator
- [ ] **Computer** with Python environment and available USB ports

### Software

- [ ] `Thruster_Test/thrust_calibration.py` - Main calibration script
- [ ] `Thruster_Test/thruster_test.py` - Optional quick verification to test that all solenoids work
- [ ] `Thruster_Test/analyze_thruster_data.py` - Analysis and reporting tool

---

## Pre-Calibration Setup

### 1. Satellite Preparation

Before mounting the thrust bench, prepare the satellite:

1. **Remove side panels**:
   - Screw off all side panels
   - Disconnect cameras from each panel
   - Disconnect distance sensors from each panel
   - Disconnect LED light from each panel
   - Set panels aside

2. **Remove thruster nozzles**:
   - Unscrew nozzles from all 8 thrusters
   - Keep nozzles in safe location (will reinstall after calibration)

3. **Prepare for tube connections**:
   - Each thruster being tested will connect via push-to-connect fitting

### 2. Thrust Bench Setup and Mounting

The thrust bench is used to measure thruster force output.

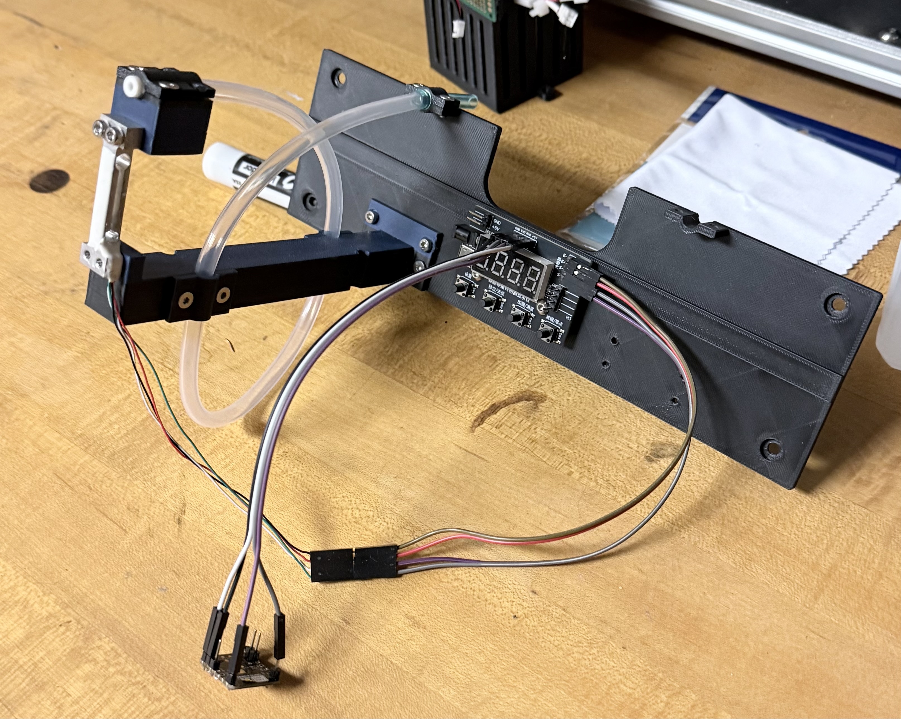
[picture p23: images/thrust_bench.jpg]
Fully assembled thrust bench with HX711 load cell and ESP32-S3

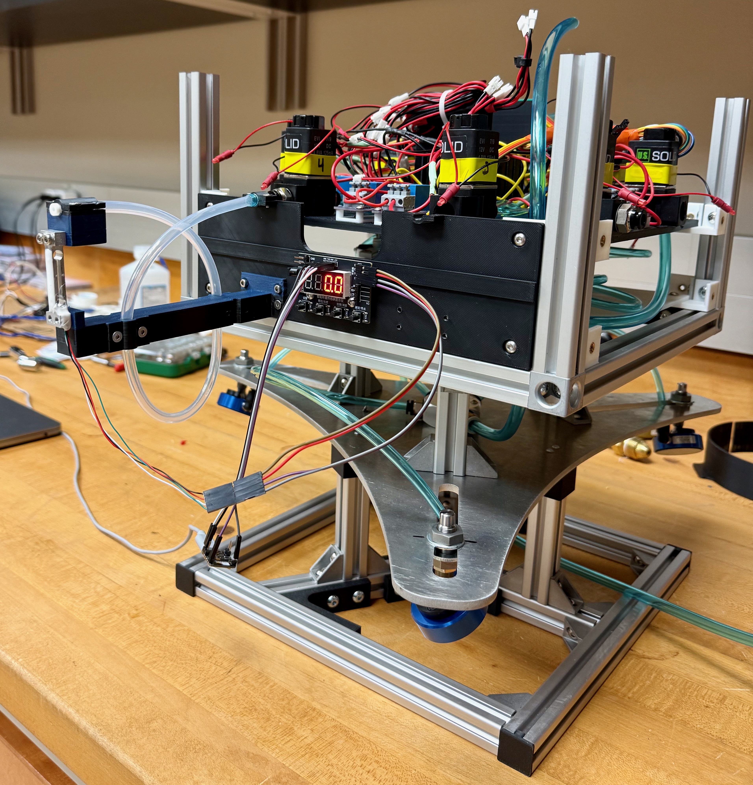
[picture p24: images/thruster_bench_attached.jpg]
Thrust bench attached to satellite calibration


**CRITICAL - Satellite Must Be on Stand**: During calibration, the satellite **must be placed on a test stand** (not floating on the floor). The satellite should NOT be on air bearings during thrust calibration testing. This keeps the satellite stable and prevents unwanted motion during measurements.

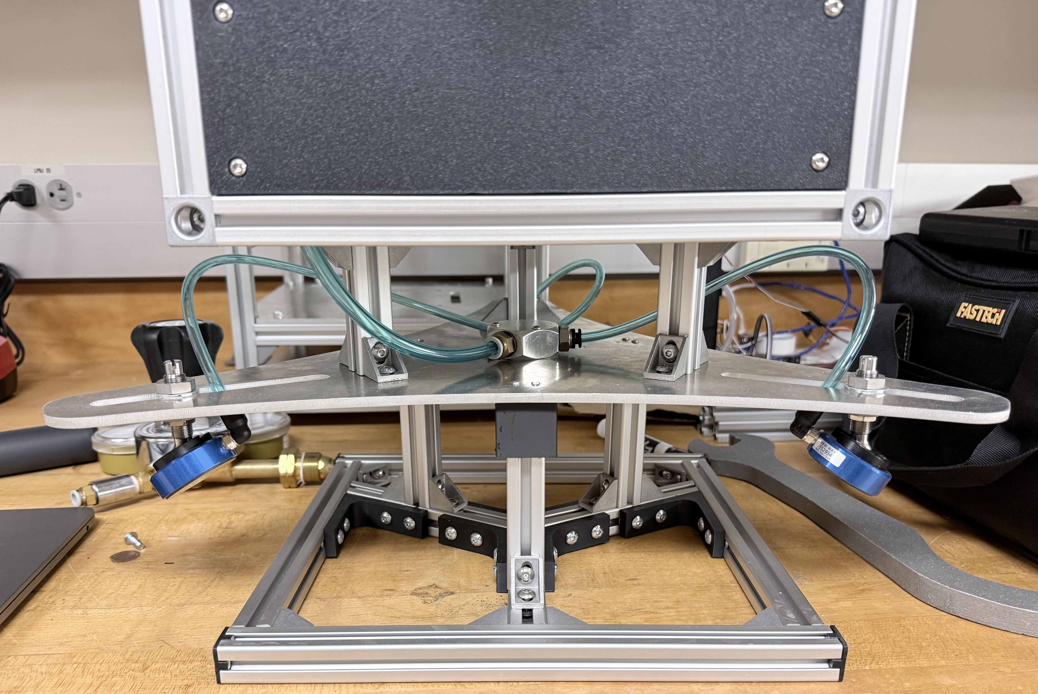
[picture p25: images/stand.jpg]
Satellite on test stand for thruster calibration


1. **Prepare thrust bench**:
   - Ensure HX711 module is mounted securely to bench
   - Verify load cell is properly calibrated (see Load Cell Calibration below)
   - Check all mechanical connections are tight
   - Check all wires are connected
  
2. **Install push-to-connect fittings**:
   - Screw a 6mm OD push-to-connect fitting onto the thruster nozzle port
   - Use 6mm OD tubing to connect from fitting to thrust bench
   - Ensure tight connection (no air leaks)

3. **Mount thrust bench to satellite**:
   - Attach thrust bench to the satellite structure
   - Ensure stable, rigid mounting (no flex or movement)
   - Push the 6mm OD tubing into the push to connect fitting
   - Ensure tight connection (no air leaks)

### 3. Load Cell Calibration (CRITICAL - DO BEFORE EACH TEST)

**IMPORTANT**: The load cell must be calibrated before each test to ensure accurate measurements.

**Load cell specifications**:
- **Maximum rated capacity**: 100 grams
- **WARNING**: Exceeding 100g will break the load cell and give inaccurate readings
- **Calibration frequency**: Before each test

**Calibration procedure**:

1. **Disconnect the thrust bench** from any air supply
2. **Ensure load cell free hanging** no force applied to the load cell other then gravity
3. **Use a known small weight** (recommend 20g-50g calibration weight)

4. **Tare the load cell**:
   - Use the calibration button on the HX711 module
   - Place the thrust bench so that the load cell is hanging freely and only supported at the base where it is connected to the thrust bench
   - Press "tare" or "zero" to set baseline
   - Load cell should read 0g

5. **Calibration**:
   - Place 50g test weight on load cell
   - Using the button on the HX711 module input the know weight(50gr) and press OK
   - Verify reading shows approximately 50g
   - Remove weight and verify it returns to 0g
   - Put the load back on the load cell and verify it reads 50g
   - Load cell is now calibrated and ready

**If calibration is incorrect**:
- Do NOT use load cell for testing
- Load cell may be damaged or need recalibration

### 4. Hardware Connections

**CRITICAL**: The satellite must be powered and the ESP32 gateway must be connected so the system can send commands to open/close thruster solenoid valves.

1. **Power the satellite**:
   - Install both 12V batteries into battery adapters (see HARDWARE_TEST_PROCEDURE.md section 1)
   - Turn ON both battery power switches
   - Verify battery voltage is adequate
   - **Both batteries must be ON for thruster command communication**

2. **Connect ESP32 gateway to computer**:
   - Plug USB cable from ESP32 gateway into computer
   - Note the serial port (e.g., `/dev/tty.usbserial-XXXXX` on macOS)
   - Gateway must be connected for thrust_calibration.py to send solenoid commands

3. **Connect ESP32 microcontroller (load cell) to computer**:
   - Plug USB cable from ESP32 (on thrust bench) into computer
   - Note the serial port for the load cell microcontroller
   - This receives force measurements from HX711

4. **Verify air system**:
   - Verify air lines are connected from air supply to solenoid valves
   - Air bearing valve should be CLOSED (no air to bearings during calibration)
   - Thruster valve should be OPEN (air flowing to thrusters)
   - Check for any loose connections

### 5. Air System Verification

Before calibration, verify the air system is properly configured:

1. **Air bearing valve**: CLOSED
2. **Thruster valve**: OPEN (air flowing to thrusters)
3. **Air supply**: Connected to thruster regulator

**Standard calibration pressure**: 40 PSI (Check if desired thrust is feasible using simulation.py if changing from 40 psi)

### 6. Identify Serial Ports for Both Microcontrollers

You have TWO microcontrollers connected that require different serial ports:
1. **ESP32 gateway** - sends commands to thrusters
2. **Xiao ESP32-S3** - reads force from load cell

Identify both ports:

**On macOS/Linux:**
```bash
ls /dev/tty.*
```

You should see two ports like:
- `/dev/tty.usbserial-XXXXX` - ESP32 gateway
- `/dev/tty.usbserial-YYYYY` - Xiao ESP32-S3 (load cell)

**On Windows:**
- Open Device Manager → Ports (COM & LPT)
- Note the two COM ports (e.g., COM20 and COM21)

**Tip**: Disconnect one USB cable at a time to identify which port is which.

### 7. Update thrust_calibration.py with Serial Ports

Edit `Thruster_Test/thrust_calibration.py` and update the serial ports:

**Find and update the GATEWAY serial port** (sends thruster commands):
```python
GATEWAY_SERIAL_PORT = '/dev/tty.usbserial-12345'  # ESP32 gateway port
# or
GATEWAY_SERIAL_PORT = 'COM20'                      # Windows example
```

**Find and update the LOAD CELL serial port** (reads force measurements):
```python
LOADCELL_SERIAL_PORT = '/dev/tty.usbserial-67890'  # Xiao ESP32-S3 port
# or
LOADCELL_SERIAL_PORT = 'COM21'                      # Windows example
```

Save the file after updating both ports.

**Important**: Use the correct port for each microcontroller or the calibration will fail.

---

## Running Calibration

### Quick Verification (Optional First Step)

Before full calibration, verify all 8 thrusters respond to commands:

```bash
cd Thruster_Test
python3 thruster_test.py
```

**Expected behavior**:
- Each thruster fires for 1 second sequentially
- All 8 thrusters should respond without delays
- No error messages in terminal
- Solenoid valves should click audibly

If any thruster doesn't fire, **stop and troubleshoot** (see Troubleshooting section).

### Full Calibration Test

**Run the calibration script:**

```bash
cd Thruster_Test
python3 thrust_calibration.py
```

**Test procedure (for your thrust bench setup)**:

1. **Select single thruster mode**
2. **Run each thruster twice consecutively**
   - First test (Test 1)
   - Second test (Test 2)
3. **Move to next thruster** and repeat
4. **Complete all 8 thrusters** with 2 tests each

**Recommended workflow:**

```bash
# First complete pass through all 8 thrusters (Test 1 each)
# Thruster 1 - Test 1
# Thruster 2 - Test 1
# ... Thruster 8 - Test 1

# Then repeat for second pass through all 8 thrusters (Test 2 each)
# Thruster 1 - Test 2
# Thruster 2 - Test 2
# ... Thruster 8 - Test 2
```

### During Calibration

**What to monitor:**

1. **Load cell readings - CRITICAL**:
   - **DO NOT EXCEED 100 GRAMS** on the load cell
   - If reading approaches 100g, **STOP immediately** and reduce air pressure
   - Exceeding 100g will break the load cell and render it unusable
   - Load cell will give inaccurate readings if overloaded
   - Typical safe range: 20-80g per thruster
   - If a thruster produces >100g: reduce regulator pressure and recalibrate

2. **Terminal output** - Shows real-time progress:
   ```
   [INFO] Testing Thruster 1...
   [INFO] Pulse 1/15 - Firing thruster...
   [INFO] Force readings: min=50g, max=80g, mean=70g
   ```

3. **Load cell force values** - Forces should be:
   - Positive values (grams-force)
   - Stable and repeatable across all 15 pulses
   - Well below 100g limit (target: 50-80g range)
   - Consistent between Test 1 and Test 2 for each thruster

4. **Audible feedback** - You should hear:
   - Solenoid valve clicks (normal)
   - Compressed air discharge (expected)

5. **Air pressure** - Monitor that:
   - Pressure remains stable at your test pressure
   - No sudden drops (indicates leak or insufficient air pressure supply)

### Data Collection

During each test, CSV files are automatically generated and saved:

**CSV files are created in**: `Thruster_Test/Thruster_Data/`

**File naming format**:
```
MPC_Thruster(N)_YYYYMMDD_HHMMSS.csv
```

Example:
```
Thruster_Test/Thruster_Data/
├── MPC_Thruster(1)_20250116_143022.csv    # Thruster 1 - Test 1
├── MPC_Thruster(1)_20250116_143522.csv    # Thruster 1 - Test 2
├── MPC_Thruster(2)_20250116_145022.csv    # Thruster 2 - Test 1
├── MPC_Thruster(2)_20250116_145522.csv    # Thruster 2 - Test 2
├── ...
└── MPC_Thruster(8)_20250116_165522.csv    # Thruster 8 - Test 2
```

**Each CSV file contains**:
- **t_s**: Time in seconds
- **weight_g**: Load cell reading in grams-force
- **bitmask**: Which thruster(s) are active
- **pulse_number**: Which pulse (1-15)
- **phase**: Test phase (baseline, pre_pulse, firing, post_pulse, pause)

---

## Analyzing Results

After all 8 thrusters have been tested twice, you now have 16 CSV files in `Thruster_Test/Thruster_Data/`. The next step is to analyze these files to extract the mean thrust values for each thruster.

### Analysis Workflow Overview

```
1. Run thrust_calibration.py twice per thruster
   ↓
2. 16 CSV files generated (2 per thruster)
   ↓
3. Run analyze_thruster_data.py
   ↓
4. Extract mean thrust values per thruster
   ↓
5. Update SET_EFFECTS matrix in config
```

### Running the Analysis Script

After all calibration tests are complete, run the analysis tool:

```bash
cd Thruster_Test
python3 analyze_thruster_data.py
```

The script will prompt you to select analysis mode. For your thrust bench calibration, use:

```bash
cd Thruster_Test
python3 analyze_thruster_data.py multi
```

This will analyze both test runs for each thruster and generate **mean thrust values**.

### Analysis Output - Mean Thrust Values

**The analysis generates:**
- **Mean thrust per thruster** - Average of Test 1 and Test 2 
- Peak thrust values
- Consistency metrics (standard deviation)
- Coefficient of variation (repeatability %)
- Summary report with all 8 thrusters

**Example output:**
```
Thruster Analysis Results
=========================

Thruster 1:
  - Test 1 thrust: 2.156 N
  - Test 2 thrust: 2.152 N
  - Mean thrust: 2.154 N (use this value)
  - Std Dev: 0.002 N
  - Consistency: 99.9%

Thruster 2:
  - Test 1 thrust: 2.142 N
  - Test 2 thrust: 2.138 N
  - Mean thrust: 2.140 N (use this value)
  - Std Dev: 0.003 N
  - Consistency: 99.8%

... (continues for Thrusters 3-8)
```

### Single Test Analysis (Optional)

To analyze a single CSV file in detail:

```bash
cd Thruster_Test
python3 analyze_thruster_data.py single Thruster_Data/MPC_Thruster\(1\)_20250116_143022.csv
```

**Output includes:**
- Peak thrust
- Mean thrust
- Median thrust
- Standard deviation (consistency measure)
- Coefficient of variation (%)
- 75th and 90th percentile values
- Visualization plots (10 graphs)

### Cross-Thruster Comparison (Optional)

Compare all 8 thrusters to verify uniformity:

```bash
cd Thruster_Test
python3 analyze_thruster_data.py compare
```

**Output includes:**
- Thrust comparison across all 8 thrusters
- Fleet mean and standard deviation
- **Uniformity grade** (Excellent/Good/Fair/Poor)
- **Reliability grade** (based on test consistency)
- Best/worst performing thrusters
- Thrust range (min to max)

**Important**: Thrusters should be within **±10% of each other** for good attitude control.

### Complete Analysis Pipeline (Recommended)

Run all analysis types with one command:

```bash
cd Thruster_Test
python3 analyze_thruster_data.py all
```

This generates:
- Single test reports for each CSV file
- Multi-test summaries and mean thrust values
- Cross-thruster comparison
- Comprehensive MPC configuration recommendations

---

## Updating Configuration

### Step 1: Extract Mean Thrust Values from Analysis

After running `analyze_thruster_data.py multi`, extract the **mean thrust values** for each thruster from the output. These are the average values from Test 1 and Test 2 for each thruster.

**Example mean thrust values**:
```
Thruster 1: 0.154 N
Thruster 2: 0.140 N
Thruster 3: 0.149 N
Thruster 4: 0.146 N
Thruster 5: 0.143 N
Thruster 6: 0.157 N
Thruster 7: 0.152 N
Thruster 8: 0.148 N
```

### Step 2: Update MPC Configuration with Mean Thrust Values

Edit `config/physics.py` and update the `THRUSTER_FORCES` matrix with your mean thrust values:

```python
# Update with YOUR calibrated mean thrust values from analyze_thruster_data.py
THRUSTER_FORCES = {
    1: 0.441450,  # N - Measured thruster forces
    2: 0.430659,
    3: 0.427716,
    4: 0.438017,
    5: 0.468918,
    6: 0.446846,
    7: 0.466956,
    8: 0.484124,
}
```

> **File location**: `config/physics.py`

---

## Troubleshooting

### Load Cell Overload or Damage

**Symptoms**: Load cell readings suddenly become erratic, negative, or jump wildly. Or load cell exceeded 100g during testing.

**CRITICAL - Do NOT continue testing!**

1. **Stop all tests immediately**
2. **Disconnect air supply** to thrusters
3. **Inspect load cell**:
   - Verify wiring connections are good
   - Recalibrate and check values again, if still behaving erratic most likely the load cell is damaged

**If load cell was overloaded**:
- Load cell may be permanently damaged
- Readings will be inaccurate

**Prevention**:
- Always monitor load cell readings during testing
- Stop immediately if reading approaches 100g
- Reduce air pressure if thrusters produce excessive force
- Calibrate load cell before each test

### Serial Port Issues

**Error**: `Serial port not found` or `Could not connect to load cell`

**Solutions**:
1. Verify USB cables are properly connected
2. Check Device Manager / System Preferences for ports
3. Try unplugging and replugging USB cables
4. Restart Python script
5. Check that the correct baud rate is used (115,200)

### Thruster Won't Fire

**Symptoms**: No air discharge, no solenoid click, load cell shows no force

**Causes and fixes**:
1. **Battery power OFF**:
   - Verify 12V battery switch is ON
   - Check battery charge level
   - Ensure battery connections are secure

2. **Wiring loose**:
   - Verify all wires to solenoid valves are connected
   - Check for pinched or damaged wires
   - Verify bitmask in calibration matches thruster mapping
  
3. **Insufficient Battery Power**:
   - Measure the voltage from the battery
  
4. **Burned relay or solenoid**:
   - Try paring with a relay from another solenoid
   - Try pairing the solnoid with another relay

### Load Cell Not Reading Force

**Symptoms**: Load cell shows 0g even when thruster fires

**Causes and fixes**:
1. **Load cell not properly zeroed**:
   - Run zero calibration on load cell
   - Verify scale shows 0g when no load applied

2. **Serial connection to load cell**:
   - Verify load cell USB cable is connected
   - Check port identification
   - Try different USB port on computer

### Inconsistent Thrust Values

**Symptoms**: Median thrust varies wildly between tests, high coefficient of variation (>15%)

**Causes and fixes**:
1. **Air pressure fluctuating**:
   - Check main regulator is stable at 40 PSI
   - Look for slow leaks reducing pressure over test
   - Verify air supply is adequate

2. **Solenoid valve sticking**:
   - Clean or replace solenoid valve
   - Check for air system contamination
   - Run short burst tests to verify responsiveness

---

## Complete Calibration Workflow Summary

Here's the end-to-end process from testing to deployment:

```
┌─────────────────────────────────────────────────────────────┐
│ 1. PREPARE                                                  │
│   - Place satellite on test stand (NOT floating)            │
│   - Remove side panels and nozzles                          │
│   - Mount thrust bench to satellite                         │
│   - Calibrate load cell (100g limit!)                       │
│   - Connect ESP32 for load cell and identify serial port    │
│   - Connect ESP32 for gateway and identify serial port      │
│   - Power on 12V batteries                                  │
│   - Close air bearing valve, open thruster valve            │
└─────────────────────────────────────────────────────────────┘
                          ↓
┌─────────────────────────────────────────────────────────────┐
│ 2. TEST                                                     │
│   - Run thrust_calibration.py twice per thruster            │
│   - 16 CSV files generated (2 per thruster)                 │
│   - Monitor load cell (never exceed 100g!)                  │
│   - Files saved to: Thruster_Test/Thruster_Data/            │
└─────────────────────────────────────────────────────────────┘
                          ↓
┌─────────────────────────────────────────────────────────────┐
│ 3. ANALYZE                                                  │
│   - Run: python3 analyze_thruster_data.py multi             │
│   - Extract mean thrust values for each thruster            │
│   - Verify uniformity                                       │
│   - Review consistency metrics                              │
└─────────────────────────────────────────────────────────────┘
                          ↓
┌─────────────────────────────────────────────────────────────┐
│ 4. UPDATE CONFIG                                            │
│   - Edit config/physics.py                                  │
│   - Update THRUSTER_FORCES matrix with mean thrust values   │  
└─────────────────────────────────────────────────────────────┘
                          ↓
┌─────────────────────────────────────────────────────────────┐
│ 5. REASSEMBLE                                               │
│   - Disconnect 6mm tubing and fittings                      │
│   - Remove thrust bench from satellite                      │
│   - Reinstall all thruster nozzles                          │
│   - Reconnect side panels and all connections               │
└─────────────────────────────────────────────────────────────┘
                          ↓
┌─────────────────────────────────────────────────────────────┐
│ 6. VERIFY                                                   │
│   - Run test mission with new thrust values                 │
│   - Verify control quality                                  │
│   - Satellite is now calibrated and ready for operations    │
└─────────────────────────────────────────────────────────────┘
```

---

## When to Recalibrate

Recalibrate thrusters if:

- **Pressure changed**: Different regulator setting requires recalibration
- **Thruster replaced**: New solenoid valve or nozzle
- **Suspect degradation**: Inconsistent behavior or reduced thrust
- **After major test series**: Verify no damage or wear

---

## Reference

### File Locations

| Component | File | Purpose |
|---|---|---|
| Calibration script | `Thruster_Test/thrust_calibration.py` | Run calibration |
| Quick test | `Thruster_Test/thruster_test.py` | Verify responsiveness |
| Analysis tool | `Thruster_Test/analyze_thruster_data.py` | Analyze results |
| Data files | `Thruster_Test/Thruster_Data/` | CSV calibration data |
| Configuration | `config/physics.py` | Update THRUSTER_FORCES |

### Quick Command Reference

```bash
# Quick thruster verification
python3 Thruster_Test/thruster_test.py

# Run full calibration for all 8 thrusters
cd Thruster_Test && python3 thrust_calibration.py

# Analyze single test
python3 analyze_thruster_data.py single <filename>

# Multi-test analysis per thruster
python3 analyze_thruster_data.py multi

# Cross-thruster comparison
python3 analyze_thruster_data.py compare

# Complete pipeline (all analysis types)
python3 analyze_thruster_data.py all
```

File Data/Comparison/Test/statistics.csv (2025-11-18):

Metric | Real Test | Simulation | Absolute Error | Error %
Position Error Mean (m) | 0.1791 | 0.2167 | 0.0376 | 20.99
Position Error Max (m) | 0.9328 | 0.9339 | 0.0011 | 0.12
Position Error Std (m) | 0.1157 | 0.1253 | 0.0096 | 8.30
Final Position Error (m) | 0.0241 | 0.0013 | 0.0228 | 94.61
Angle Error Mean (deg) | 12.72 | 13.42 | 0.7000 | 5.50
Angle Error Max (deg) | 80.42 | 80.43 | 0.0100 | 0.01
Final Angle Error (deg) | 0.51 | 0.18 | 0.3300 | 64.71
Velocity Mean (m/s) | 0.0630 | 0.0642 | 0.0012 | 1.90
Velocity Max (m/s) | 0.1267 | 0.1214 | 0.0053 | 4.18
Final Velocity (m/s) | 0.0051 | 0.0006 | 0.0045 | 88.24
Thruster T1 Duty (%) | 14.13 | 5.63 | 8.5000 | 60.16
Thruster T2 Duty (%) | 15.93 | 5.48 | 10.4500 | 65.60
Thruster T3 Duty (%) | 7.58 | 9.33 | 1.7500 | 23.09
Thruster T4 Duty (%) | 11.74 | 9.85 | 1.8900 | 16.10
Thruster T5 Duty (%) | 7.98 | 10.57 | 2.5900 | 32.46
Thruster T6 Duty (%) | 8.78 | 27.08 | 18.3000 | 208.43
Thruster T7 Duty (%) | 12.48 | 7.82 | 4.6600 | 37.34
Thruster T8 Duty (%) | 17.22 | 20.57 | 3.3500 | 19.45
Avg Thrusters Active | 0.96 | 0.96 | 0.0000 | 0.00
Total Thrust Usage (s) | 188.04 | 190.80 | 2.7600 | 1.47
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

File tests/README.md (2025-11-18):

# Tests

This directory is for unit tests and integration tests for the Satellite Thruster Control System.

## Running Tests

Once tests are added, you can run them with:

```bash
python3 -m pytest tests/
```

## Test Structure

- `test_mpc_controller.py` - Tests for MPC controller
- `test_config.py` - Tests for configuration validation
- `test_model.py` - Tests for physical model
- `test_mission_state_manager.py` - Tests for mission logic
- `test_integration_basic.py` - Basic integration tests
- `test_integration_missions.py` - Mission integration tests
- Additional test files as needed

## Testing Tools

For manual testing and verification:
- Use `testing_environment.py` for interactive manual control
- Use `comparison.py` for comparing simulation vs real test data

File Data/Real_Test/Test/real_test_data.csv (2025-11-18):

Step | MPC_Start_Time | Control_Time | Actual_Time_Interval | CONTROL_DT | Telemetry_X_mm | Telemetry_Z_mm | Telemetry_Yaw_deg | Current_X | Current_Y | Current_Yaw | Current_VX | Current_VY | Current_Angular_Vel | Target_X | Target_Y | Target_Yaw | Error_X | Error_Y | Error_Yaw | MPC_Computation_Time | MPC_Status | MPC_Solver | MPC_Solver_Time_Limit | MPC_Solve_Time | MPC_Time_Limit_Exceeded | MPC_Fallback_Used | MPC_Objective | Command_Vector | Command_Hex | Command_Sent_Time
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

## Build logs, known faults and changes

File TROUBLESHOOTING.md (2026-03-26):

# Troubleshooting Guide

Common issues and solutions for the Satellite Thruster Control System.

---

## Table of Contents

- [Installation Issues](#installation-issues)
- [Runtime Errors](#runtime-errors)
- [Hardware Issues](#hardware-issues)
- [Performance Issues](#performance-issues)
- [Data Analysis Issues](#data-analysis-issues)
- [Getting Help](#getting-help)

---

## Installation Issues

### Python Version Incompatibility

**Problem**: "Python 3.13+ not supported" or packages fail to install

**Solution**:
```bash
# Check your Python version
python3 --version

# Must be Python 3.9, 3.10, 3.11, or 3.12
# Download from https://www.python.org/downloads/

# Alternative: Use pyenv for version management
pyenv install 3.12.0
pyenv local 3.12.0

# Alternative: Use conda
conda create -n satellite python=3.12
conda activate satellite
```

### "ModuleNotFoundError: No module named 'gurobipy'"

**Problem**: Gurobi not installed or license not found

**Solution**:
```bash
# 1. Install Gurobi
pip install gurobipy

# 2. Get academic license (free)
# - Visit: https://www.gurobi.com/academia/academic-program-and-licenses/
# - Register with .edu email
# - Download gurobi.lic file

# 3. Place license file in project root (local only, gitignored)
cp ~/Downloads/gurobi.lic /path/to/mpc-air-bearing-satellite/

# 4. Verify installation
python3 -c "import gurobipy as gp; print('Gurobi OK')"
```

### "ModuleNotFoundError" for other packages

**Problem**: Missing dependencies (numpy, scipy, etc.)

**Solution**:
```bash
# Reinstall all requirements
pip install --upgrade -r requirements.txt

# Or individually:
pip install numpy scipy matplotlib pyqt5 opencv-python pandas seaborn
pip install gurobipy pyserial ezdxf shapely flask flask-cors
```

### FFmpeg Not Found

**Problem**: "ffmpeg not found" when generating videos

**Solution (macOS)**:
```bash
brew install ffmpeg
```

**Solution (Linux - Ubuntu/Debian)**:
```bash
sudo apt update
sudo apt install ffmpeg
```

**Solution (Linux - Fedora/RHEL)**:
```bash
sudo dnf install ffmpeg
```

**Solution (Windows)**:
1. Download from: https://ffmpeg.org/download.html
2. Extract to a folder (e.g., `C:\ffmpeg`)
3. Add to PATH:
   - Search "Edit environment variables"
   - Add `C:\ffmpeg\bin` to PATH
4. Verify: `ffmpeg -version`

### Virtual Environment Issues

**Problem**: Dependencies installed but imports still fail

**Solution**:
```bash
# Create fresh virtual environment
python3 -m venv venv
source venv/bin/activate  # On Windows: venv\Scripts\activate

# Install from requirements
pip install -r requirements.txt
```

---

## Runtime Errors

### "GurobiError: Model too large for license"

**Problem**: Trial license doesn't support problem size

**Solution**:
1. Get academic license (free, larger limits)
   - Follow Gurobi installation steps above
2. Reduce problem size temporarily:
   ```python
   # In config/mpc_params.py
   MPC_PREDICTION_HORIZON = 10  # Reduce from default
   MPC_CONTROL_HORIZON = 8
   ```

### "Solver time limit exceeded"

**Problem**: MPC solver takes too long to run

**Solutions**:
```python
# Reduce prediction horizon
# config/mpc_params.py
MPC_PREDICTION_HORIZON = 12  # Reduce from 15

# Reduce control horizon
MPC_CONTROL_HORIZON = 8  # Reduce from 10

# Increase time limit (short-term fix)
MPC_SOLVER_TIME_LIMIT = 0.05  # 50ms instead of 40ms
# (But keep < control timestep!)
```

### "Timing violation" in simulation

**Problem**: "Timing violation" messages in log, or simulation pauses

**Solution**:
```python
# config/timing.py
CONTROL_DT = 0.02  # Increase timestep from 0.01
# or reduce prediction horizon (see above)
```

### Serial Port Errors on Linux

**Problem**: "Permission denied" or "Serial port not found"

**Solution**:
```bash
# Add user to dialout group
sudo usermod -a -G dialout $USER

# Log out and back in (or restart)
exit  # Log out
# Log back in

# Verify
ls -l /dev/ttyUSB*  # Should show permissions
```

### Serial Port Errors on macOS

**Problem**: "Serial port not found"

**Solution**:
```bash
# Find port name
ls /dev/tty.*
# Output might be: /dev/tty.usbserial-14110

# Update config in config/constants.py (line 55)
SERIAL_PORT = '/dev/tty.usbserial-14110'
```

### Serial Port Errors on Windows

**Problem**: "COM port not found" or "Invalid port"

**Solution**:
1. Open Device Manager:
   - Search "Device Manager"
   - Look under "Ports (COM & LPT)"
   - Note the COM port number (e.g., COM20)

2. Update config:
   ```python
   # In satellite_config.py
   SERIAL_PORT = 'COM20'
   ```

3. Check permissions:
   - Run Python as Administrator if access denied

### Import Errors with PyQt5

**Problem**: Qt conflicts between conda and pip

**Solution**:
```bash
# Use only conda for PyQt5
conda install pyqt5

# Don't mix conda and pip for Qt packages
pip uninstall pyqt5
```

---

## Hardware Issues

### Hardware Tests Fail Immediately

**Problem**: "Real.py fails with safety check error"

**Solutions**:
1. **Check Motive Server**:
   ```bash
   cd Motive
   python3 motive_data_server.py
   # Should output: "Listening on port 1111"
   ```

2. **Verify Satellite Visible in Motive**:
   - Open Motive GUI
   - Confirm markers show in 3D view
   - Confirm orbit/pose estimation is active

3. **Check Serial Connection**:
   ```bash
   # Test serial port
   python3 -c "
   import serial
   ser = serial.Serial('/dev/ttyUSB0', 115200)
   print('Connected!')
   ser.close()
   "
   ```

4. **Check Air Supply**:
   - Verify compressed air is on
   - Check pressure gauge (should be 60-80 PSI)

5. **Check Starting Position**:
   - Satellite must be in workspace bounds
   - See config/mpc_params.py: WORKSPACE_X, WORKSPACE_Y

### Satellite Won't Hover (Air Bearing Issue)

**Problem**: Satellite tilts excessively or won't float

**Solutions**:
1. **Check Floor Levelness**:
   ```bash
   # Use spirit level
   # Acceptable: < 0.5° tilt
   ```

2. **Adjust Air Bearing Pressure**:
   ```bash
   # Increase pressure gradually (10 → 80 PSI)
   # Adjust needle valves for balanced height
   ```

3. **Check for Air Leaks**:
   ```bash
   # Listen for hissing
   # Check all connections
   # Inspect for debris
   ```

4. **Clean Air Bearings**:
   ```bash
   # Turn off air supply
   # Inspect for dirt/particles
   # Clean gently with cloth
   ```

### Thrusters Don't Fire

**Problem**: "Thruster command sent but no movement"

**Solutions**:
1. **Verify Solenoid Power**:
   - Check 24V power to manifold
   - Use multimeter to verify voltage

2. **Test Solenoid Valve**:
   - Connect 24V directly to valve
   - Listen for clicking sound
   - Check for air flow at output

3. **Check Serial Command**:
   ```bash
   # Monitor serial with logic analyzer
   # Verify bitmask is correct
   # Check baud rate is 115200
   ```

4. **Verify Air Supply**:
   - Check pressure gauge
   - Check for kinks in tubing
   - Test manifold input directly

5. **Test Microcontroller**:
   ```cpp
   // In Arduino sketch, test directly:
   digitalWrite(THRUSTER_PIN, HIGH);
   delay(500);
   digitalWrite(THRUSTER_PIN, LOW);
   ```

### Motion Capture Tracking Issues

**Problem**: "Motive reports low tracking quality or no markers"

**Solutions**:
1. **Check Marker Cleanliness**:
   - Clean markers with soft cloth
   - Remove any dirt/dust

2. **Verify Camera Focus**:
   - Check cameras are in focus
   - Adjust zoom if needed

3. **Check Lighting**:
   - Increase LED ring brightness
   - Ensure adequate ambient light

4. **Recalibrate Motive**:
   - Run wand calibration
   - Check calibration quality score > 0.5

5. **Check Camera Sync**:
   - Verify sync box is connected
   - Verify sync LED is on

---

## Performance Issues

### Slow Simulation

**Problem**: Simulation runs slowly or lags

**Solutions**:
```python
# Reduce simulation fidelity
# config/timing.py
SIMULATION_TIMESTEP = 0.01  # Increase from 0.005

# Reduce MPC horizon
# config/mpc_params.py
MPC_PREDICTION_HORIZON = 10  # Reduce from 15

# Disable visualization during run
# In simulation.py, disable live plotting
```

### High CPU Usage

**Problem**: Python process uses 100% CPU

**Solutions**:
1. Close other applications
2. Reduce simulation fidelity (see above)
3. Use task manager/Activity Monitor to find bottleneck
   ```bash
   # Profile code
   python3 -m cProfile -s cumulative simulation.py
   ```

### Network Latency with Motion Capture

**Problem**: "Motion capture data delayed" or "Timing violations"

**Solutions**:
1. Check network quality:
   ```bash
   ping <motive_server_ip>
   # Should be < 5ms latency
   ```

2. Use wired connection (not WiFi)

3. Reduce data rate if possible

---

## Data Analysis Issues

### CSV File Not Generated

**Problem**: "Simulation runs but no CSV file created"

**Solution**:
```bash
# Check output directory
ls Data/Simulation/
# Should contain timestamped folders

# Check permissions
# Data/ directory should be writable
chmod 755 Data/

# Check disk space
df -h
# Should have > 1GB free
```

### Video Generation Fails

**Problem**: "ffmpeg error" or no MP4 created

**Solutions**:
```bash
# Verify FFmpeg is installed
ffmpeg -version

# Check output permission
chmod 755 Data/

# Check disk space
df -h
```

### Can't Load CSV Data

**Problem**: "Error reading CSV" in data analysis

**Solution**:
```python
# Check CSV format
import pandas as pd
data = pd.read_csv('Data/Simulation/.../simulation_data.csv')
print(data.head())
print(data.info())

# Common issues:
# - Wrong delimiter (comma vs semicolon)
# - Wrong encoding (UTF-8 vs Latin-1)
# - Missing values
```

### Plotting Fails

**Problem**: "Matplotlib error" when visualizing

**Solution**:
```bash
# Verify Matplotlib installed
pip install --upgrade matplotlib

# Check display backend
python3 -c "
import matplotlib
print(matplotlib.get_backend())
# Should output: 'TkAgg' or similar
"
```

---

## Getting Help

### Check Documentation

1. **README.md**: Quick start and overview
2. **ARCHITECTURE.md**: System design details
3. **HARDWARE_TEST_PROCEDURE.md**: Hardware setup and testing
4. **DEVELOPMENT_GUIDE.md**: Extending the code
5. **TESTING_GUIDE.md**: Test suite
6. **CSV_FORMAT.md**: Data format

### Debug Steps

1. **Enable debug logging**:
   ```python
   import logging
   logging.basicConfig(level=logging.DEBUG)
   ```

2. **Check logs**:
   ```bash
   tail -f Data/simulation.log
   tail -f Data/real_control.log
   ```

3. **Run tests**:
   ```bash
   pytest -v
   ```

4. **Check configuration**:
   ```python
   python3 -c "
   from config import SatelliteConfig
   SatelliteConfig.validate_parameters()
   SatelliteConfig.print_thruster_forces()
   "
   ```

### Open an Issue

1. Go to: https://github.com/AevarOfjord/mpc-air-bearing-satellite/issues
2. Check if issue already exists
3. Provide:
   - Python version
   - Operating system
   - Steps to reproduce
   - Error message (full traceback)
   - Expected vs actual behavior

### Contact

- **Author**: Aevar Ofjord
- **Institution**: University of Kentucky
- **Email**: Check GitHub profile

---

**Last Updated**: November 2024

See also: [README.md](README.md), [DEVELOPMENT_GUIDE.md](DEVELOPMENT_GUIDE.md)

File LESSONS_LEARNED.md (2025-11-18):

# Lessons Learned

This document captures the complete development journey, technical breakthroughs, and lessons learned from building a functional satellite thruster control system with Model Predictive Control and includes failed approaches, design evolution, and critical insights.

---

## Table of Contents

- [Development Timeline & Major Milestones](#development-timeline--major-milestones)
- [Hardware Design & Implementation](#hardware-design--implementation)
- [Software Control Algorithm Development](#software-control-algorithm-development)
- [Critical Breakthroughs (The Big Three)](#critical-breakthroughs-the-big-three)
- [Recommendations for Future Work](#recommendations-for-future-work)
- [Conclusion](#conclusion)

---

## Development Timeline & Major Milestones

### Phase 1: Conceptualization & Initial Design
- Literature review of MPC for satellite control
- Initial hardware design concepts (multiple thruster configurations explored)
- Initial budget planning and component sourcing

### Phase 2: Hardware Prototyping
- First satellite structure built with aluminum extrusion
- Initial power system using 5x LiPo batteries (later abandoned)
- First thruster configuration testing
- Acrylic sheet integration
- **Major Issue**: Power system unreliability

### Phase 3: MPC Software Development
- Gurobi solver integration
- Initial MPC formulation (linearized dynamics)
- Physics-based simulation development
- **Major Issue**: Solver timing violations, inadequate model accuracy

### Phase 4: Simulation Refinement
- Physics model validation and tuning
- Initial cost weight optimization
- Simulation vs theoretical behavior validation
- **Achievement**: Working simulation environment

### Phase 5: First Hardware Integration Attempts
- WiFi communication implementation (FAILED - too slow)
- Initial thruster calibration using vertical test stand (INADEQUATE)
- First closed-loop hardware tests (UNSTABLE - multiple reasons)
- **Critical Realization**: Model accuracy and communication latency are showstoppers

### Phase 6: The Breakthrough Period
- **Breakthrough 1**: ESP-NOW communication protocol (<10ms latency)
- **Breakthrough 2**: In-situ thruster calibration bench
- **Breakthrough 3**: Gurobi MIPGap tuning for real-time performance
- First successful stable hardware control achieved
- Iterative testing and refinement

### Phase 7: Validation & Documentation
- Simulation vs. hardware validation
- Performance characterization across mission types
- Documentation and thesis preparation
- **Achievement**: Robust, repeatable hardware control system

**Total Development Time**: ~8 months from concept to validated system

---

## Hardware Design & Implementation

### Power System Evolution

#### Initial Design (Failed)
**Configuration**: 5x 3.7V LiPo batteries
- 3x batteries in series → ~11.1V for solenoids
- 1x battery through boost converter → 5V for relays
- 1x battery → direct power for microcontroller and sensors

**Why It Failed**:
1. **Unreliable voltage regulation**: Battery discharge curves meant voltage dropped during operation
2. **Insufficient current capacity**: Simultaneous thruster firing caused voltage sag
3. **Complex power distribution**: Multiple conversion stages introduced failure points
4. **Poor modularity**: Battery replacement required top panel to be taken off the satellite structure
5. **Safety concerns**: No battery management system, risk of over-discharge

**Quantitative Issues**:
- Voltage drop during 4+ thruster operation
- Battery life: ~15 minutes of continuous operation
- Replacement time: 15 minutes to swap all batteries and recalibrate mass distribution

#### Final Design (Successful)
**Configuration**: 2x Milwaukee M12 batteries (12V)

**Battery 1** (Solenoid Power):
- Direct 12V connection to all 8 solenoids
- Dedicated battery ensures consistent voltage under load
- Current capacity: 20A continuous (adequate for 8 solenoids @ 0.5A each)

**Battery 2** (System Power) with dual regulation:
- **Line 1**: 3.9V regulator → XIAO ESP32-S3, distance sensors and other devices
- **Line 2**: 5V regulator → 8x relay circuits for solenoid control

**Why It Succeeded**:
1. **Voltage stability**: 12V nominal voltage stays 11.8-12.2V throughout discharge
2. **Ample current capacity**: Each M12 battery can deliver 20A continuous
3. **Modularity**: Hot-swappable batteries
4. **Commercial reliability**: Milwaukee M12 system has built-in protection circuits
5. **Extended runtime**: 6.0Ah capacity provides ~45 minutes of operation

**Quantitative Improvements**:
- Voltage stability
- Runtime: 45 minutes (vs. 15 minutes)
- Swap time: 10 seconds per battery

**Design Lesson**: **Overdesign power capacity for prototypes**. Power issues create failures that are difficult to diagnose. Commercial battery systems (Milwaukee, DeWalt, etc.) provide reliability and modularity worth the extra cost and weight.

---

### Structural Design Evolution

#### Material Selection Philosophy
The structural design evolved through three iterations to arrive at optimal material usage:

**Final Material Categories**:
1. **Aluminum extrusion** (20mm × 20mm T-slot) - Satellite chassis frame
2. **Aluminum sheet** (3mm thickness) - High-load bearing surfaces
3. **3D printed PLA+** - Custom geometry brackets and enclosures

#### Evolution of Structural Design

**Iteration 1: Mixed Materials (Problematic)**
- Aluminum extrusion frame
- Acrylic side panels
- Acrylic sheets for mounting components within the satellite structure
- Aluminum fasteners throughout

**Problems with Iteration 1**:
- Acrylic panels **too brittle**: Cracked during modification for side panels and could not be water cut
- Drilling precise holes is less accurate than 3d printing holes

**Iteration 2: Aluminum + Acrylic (Better but Still Issues)**
- Replaced acrylic mounting sheets with 3D printed PLA+ inside the satellite structure
- Kept acrylic side panels
- Added 3D printed camera mounts

**Remaining Issues**:
- Acrylic side panels still difficult to modify to fit cameras and distance sensors

**Iteration 3: Aluminum + 3D Printed Only (Final)**
- Aluminum extrusion: Structural frame (290mm × 290mm × 290mm)
- Aluminum sheet: Air bearing mounting plates (supports full 23kg) and air cylinder mounting plate
- 3D printed PLA+: All panels, mounts and some brackets and fasteners

**Why Final Design Works**:
1. **Modularity**: 3D printed panels easy to modify, reprint, iterate, while the acrylic sheets were too brittle to be water cut and had to be cut using less precise methods
2. **Precision**: Instead of having to drill holes into the acrylic sheet using mounts to make holes as precise as possible, holes could be 3D printed into the 3D printed sheet instead with more accuracy 
3. **Rapid iteration**: Design change → print overnight → test next day
4. **Integration flexibility**: Heated inserts in 3D prints provide reliable threading instead of using nuts

#### Internal Mounting

**Initial Approach**: Acrylic sheet mounting plates with drilled holes and nuts to tighten everything down
- **Issues**: Modification difficult and less accurate

**Final Approach**: 3D printed mounting plates with brass heated inserts
- **Process**: Print part holes → insert brass threaded inserts
- **Accuracy**: The 3D printed holes ended up being much more accurate than the drilled holes and also provided more secure mounting using the heated inserts rather than tightening things down using nuts

---

### Satellite Geometry & Thruster Configuration

#### Design Exploration Phase
Multiple thruster configurations were explored before selecting the final square arrangement. Each configuration was evaluated using rational analysis since the simulation software was still in development at that time.
- Control authority (ability to generate forces/torques in all directions)
- Computational complexity (impact on MPC solve time)
- Fuel efficiency

#### Configurations Considered

**Option 1: Square with 8 thrusters (SELECTED)**
- Geometry: Square
- Thruster arrangement: 2 thrusters per face, 4 faces
- Orientation: Opposite faces have mirrored thruster pairs

**Option 2: Triangle with 6 thrusters**
- Geometry: Equilateral triangle
- Thruster arrangement: 2 thrusters per face, 3 faces
- Advantage: Lower complexity (6 thrusters vs. 8)
- Disadvantage: Was not sure how good it would handle sharp rotations since it could not produce pure torque like the square shape

**Option 3: Hexagon with 6 thrusters**
- Geometry: Hexagon
- Thruster arrangement: 1 thruster per face, 6 faces
- Advantage: Lower complexity (6 thrusters vs. 8)
- Disadvantage: Not sure about the torque generation

**Option 4: Hexagon with 12 thrusters**
- Geometry: Hexagon
- Thruster arrangement: 2 thrusters per face, 6 faces
- Advantage: More thrusters could improve precise movements
- Disadvantage: Higher complexity for the MPC

**Option 5: Octagon with 8 thrusters**
- Geometry: Regular octagon
- Thruster arrangement: 1 thruster per face
- Advantage: More thrusters could improve precise movements
- Disadvantage: Uncertain about torque generation capability

#### Why Square Configuration Was Selected

**Decision Factors**:

1. **Adequate Torque Generation**
   - Largest moment arm of all shapes considered
   - Can produce pure torque

2. **Computational complexity**
   - Fewer thrusters mean less computational difficulty with fewer binary variables

**Quantitative Justification**:

| Configuration | Thrusters | Pure torque | Binary vars/step | Total MPC vars (N=12) |
|---|---|---|---|---|
| Square | 8 | Yes | 8 | 96 |
| Triangle | 6 | No | 6 | 72 |
| Hexagon | 6 | No | 6 | 72 |
| Hexagon | 12 | Yes | 12 | 144 |
| Octagon | 8 | No | 8 | 96 |

**Frame Dimensions Rationale**:
- **290mm × 290mm**: Driven by moment arm and sizes of components and devices that need to fit within the structure
- Smaller frame (e.g., 200mm): Insufficient moment arm for responsive attitude control and might be hard to fit all components and devices
- Larger frame (e.g., 400mm): Unnecessarily large, increased moment arm reduces agility
- **Trade-off point**: 290mm provides sufficient torque and also enough room to fit everything within the structure

#### Future Research Opportunities
Now that simulation is validated against hardware, exploring alternative geometries could yield insights:
- **Triangle (6 thrusters)**: Can it produce the pure torque needed for sharp corners 
- **Hexagon (12 thrusters)**: Can the MPC handle this level of complexity
- **Minimum spacing study**: How small can the moment arm be before it affects performance?
- **Fuel efficiency comparison**: Which geometry minimizes thruster usage for typical missions?

---

### Communication System: The Latency Breakthrough

Communication latency was identified as a **critical bottleneck** for this closed-loop hardware control. This section documents the evolution from inadequate WiFi to the successful ESP-NOW solution.

#### The Communication Requirement

**MPC Control Loop Architecture**:
1. **Ground Station** (Desktop running Python):
   - Receives current state from motion capture (OptiTrack Motive)
   - Computes optimal control using Gurobi MPC solver
   - Sends thruster commands to satellite

2. **Satellite Onboard Controller** (XIAO ESP32-S3):
   - Receives thruster commands via wireless link to computer
   - Actuates solenoid valves (8 thrusters)

#### Iteration 1: WiFi Communication (FAILED)

**Implementation**:
- Protocol: WiFi 802.11n (2.4GHz)
- Communication: TCP sockets
- Microcontroller: XIAO ESP32-S3 (chosen for WiFi capability)
- Network: Dedicated WiFi router for satellite communication

**Measured Performance**:
- **Latency**: Estimated around 200ms
- **Jitter**: High, noticeable variation
- **Packet loss**: 2-5% under ideal conditions, 10-15% with interference
- **Throughput**: 1-2 Mbps more than needed, but latency unacceptable

**Why WiFi Failed**:
1. **Protocol overhead**: TCP handshake, acknowledgment, retransmission add latency

**Observed Hardware Behavior with WiFi**:
- Satellite motion **unstable and oscillatory**
- Control commands arrived too late → thruster firing based on stale state
- MPC predictions invalid because state has changed by time command executes
- System could not stabilize even at single waypoint

#### Iteration 2: ESP-NOW Protocol (SUCCESS)

**What is ESP-NOW?**
- Espressif's protocol for ESP32/ESP8266 devices
- **Connectionless** peer-to-peer communication (no WiFi router needed)
- Operates on WiFi hardware but bypasses WiFi protocol stack
- Maximum 250 bytes per packet, up to 250kbps data rate

**Implementation**:
- Direct ESP32-to-ESP32 communication
- Ground station: ESP32 connected to laptop via USB serial (Gateway)
- Satellite: XIAO ESP32-S3 onboard controller
- Packet structure: 8 bytes (1 byte per thruster command)

**Measured Performance**:
- **Latency**: around 10ms
- **Jitter**: Very low, not noticeable
- **Throughput**: Adequate for 8-byte commands at 16.67Hz

**Why ESP-NOW Succeeded**:
1. **Minimal protocol overhead**: No TCP handshake, no acknowledgment
2. **Direct hardware-to-hardware**: Bypasses operating system network stack
3. **Optimized for low latency**: Designed for IoT sensor applications
4. **Deterministic timing**: Connectionless protocol has predictable latency

**Quantitative Comparison**:

| Metric | WiFi (Failed) | ESP-NOW (Success) |
|---|---|---|
| Typical latency | 200ms | 10ms |
| Jitter (std dev) | High | Low |
| Reliability | Unacceptable | Excellent |

**Impact on Control Performance**:
- With WiFi: **Unstable**, oscillatory, unable to hold position
- With ESP-NOW: **Stable**, precise waypoint tracking, successful at holding position

**Hardware Behavior Comparison**:
```
WiFi:
- Command sent at t=0ms    → Satellite at position X₀
- Command arrives at t=120ms → Satellite now at position X₀ + drift
- MPC predicted for X₀, but satellite is now at X₀ + drift → WRONG CONTROL

ESP-NOW:
- Command sent at t=0ms    → Satellite at position X₀
- Command arrives at t=5ms → Satellite at position X₀ + minimal drift
- MPC prediction still valid → CORRECT CONTROL
```

**The Breakthrough Moment**:
After struggling with WiFi instability and trying different ways of sending the signal through a dedicated router and so on, switching to ESP-NOW resulted in **immediate stable control signals** with no noticeable jitter and latency delay.

**Advisor Credit**: Dr. Poonawala, one of the advisors for this project, suggested using ESP-NOW after observing WiFi latency issues. This recommendation was **important** to project success.

**Lesson for Future Work**: **Communication latency is non-negotiable for MPC**. If control loop requires low latency communication, standard WiFi/Bluetooth are inadequate. ESP-NOW (for ESP32) or similar ultra-low-latency protocols are essential. Don't assume "WiFi is fast enough" without measuring actual latency under realistic conditions.

---

### Center of Mass Balancing

Achieving precise center of mass (COM) alignment with the geometric center is **critical** for the satellite dynamics. Any COM offset creates unintended torques during linear thrust, requiring corrective control.

#### Design Strategy for Symmetric Mass Distribution

**Principle**: Design all components in **symmetric pairs** or **centered placement**

**Symmetric Component Placement**:
- **4 identical faces**: Each face has same thruster configuration, same electronics mounting
- **Thrusters**: 2 per face × 4 faces = 8 total, all at identical radial distance from center
- **Electronics**: Sensors and devices distributed symmetrically

**Heavy Component Strategy**:
- **Air cylinder** (heaviest: ~8kg): Mounted **exactly** at geometric center, aligned with vertical axis

#### Handling Asymmetric Components

**Problem**: Pressure regulator (~800g) must mount to air cylinder, extends ~10cm from center

**Solution**: Air bearing placement adjustability

**Design Implementation**:
- Base platform has **three radial grooves** at 120° intervals
- Each air bearing slides along its groove (adjustable radial offset)
- Grooves allow COM correction by shifting support points

**Balancing Procedure**:
1. Assemble satellite with all components
2. Place the satellite on precision scales where each air bearing rests on a separate scale, measure total mass (23kg measured)
3. Adjust air bearing positions radially to compensate for imbalance
4. Iterate until all scales are within 50g of each other
5. Add small sliding weights on the structure to account for minimal remaining error

**Achieved Performance**:
- **Total mass**: 23.0kg
- **COM error**: 20g mass equivalent
- **Percentage error**: 0.09% of total mass

**Design Lesson**: **Adjustability is more important than perfect initial placement**. The radial air bearing slides allowed for post-assembly COM correction without rebuilding the structure. Plan for adjustment mechanisms in your design rather than assuming perfect manufacturing/assembly.

---

### Thruster Calibration: The Critical Hardware Breakthrough

This was **the most important hardware breakthrough** of the entire project. Accurate thruster characterization is **non-negotiable** for model-based control like MPC.

#### The Core Problem: Model-Reality Mismatch

**MPC Fundamentals**:
- MPC is a **model-based** controller
- Solver predicts future states using satellite dynamics model
- Model includes thrust forces: F = f(command)
- **If model is wrong, predictions are wrong → control fails**

**Initial Situation**:
- Simulation: MPC controller works perfectly, satellite tracks trajectories
- Hardware: MPC controller **completely unstable**, satellite uncontrollable
- **Root cause**: Simulated results did not match real satellite behavior. The simulated results would do what was expected and stabilize at a target, but the hardware would never reach the target. Error was caused by using estimated thrust forces based on pressure and velocity calculations rather than actual measured values

#### Iteration 1: Vertical Test Stand (INADEQUATE)

**Setup**:
- 3D printed bracket holds thruster **vertical**
- Thruster fires **downward** onto digital scale
- Scale measures force
- Record force generated

**Procedure**:
1. Mount thruster in vertical bracket (requires removing thruster from satellite)
2. Connect air supply with regulator set to 40 PSI
3. Fire thruster
4. Record scale reading over several seconds
5. Use the mean values of the stable force period

**Problems with Vertical Test Stand**:

1. **Measurement accuracy limited**:
   - Kitchen scale: ±1g accuracy (±0.01N force error)
   - Systematic errors (mounting, airflow) are larger than measurement noise

2. **Cannot test in actual flight configuration**:
   - Must remove thruster from satellite
   - Impossible to verify all 8 thrusters without disassembly

**Hardware Performance with Vertical Calibration**:
- MPC controller **unstable**
- Satellite either over-responds (too much thrust assumed) or under-responds (too little thrust)
- No amount of MPC tuning could achieve stability
- **Conclusion**: Model inaccuracy exceeded what controller could compensate for

#### Iteration 2: In-Situ Calibration Bench (BREAKTHROUGH)

**Design Philosophy**: **Measure thrusters in their exact flight configuration**

**Key Insight**: To get accurate thrust measurements, the thruster must be:
1. Mounted exactly as it will be in flight (same mounting hardware, same position)
2. Measured with higher accuracy than kitchen scale (±0.02g vs ±1g)

**Calibration Bench Design**:

**Mechanical Structure** (3D printed):
1. **Main bracket**: Replaces satellite side panel, uses same mounting holes
2. **Load cell mount**: Attaches 100g load cell to the bracket

**Thrust Measurement Path**:
1. Thruster fires horizontally
2. Remove 3D printed nozzle, replace with **push-to-connect fitting**
3. Silicone tubing connects thruster to a **replica nozzle** with same internal geometry as the nozzle normally mounted to the thruster
4. Replica nozzle mounted to **100g load cell** (±0.02g = ±0.0002N accuracy)
5. Tubing looped and secured to prevent sagging/tension on load cell (confirmed with multiple tests where the load cell value would return to original value before testing)
6. Load cell measures force transmitted to the replica nozzle through the silicone tube

**Critical Design Features**:

1. **Thruster never moved**: Stays in exact flight mounting location
   - Same air supply plumbing
   - Same power supply as in flight

2. **Identical nozzle geometry**: Replica nozzle has identical internal flow path
   - 3D printed with same printer, same settings as the regular nozzles attached to each solenoid
   - Only difference: Mounting for load cell instead of direct satellite mount using threads
   - Preserves airflow characteristics

3. **High-precision load cell**:
   - 100g capacity
   - ±0.02g accuracy (±0.0002N)
   - **More accurate** than kitchen scale
   - Calibrated against known precision weights before use

**Calibration Procedure**:

1. Calibrate load cell
2. Mount bracket to satellite (replaces one side panel)
3. Remove thruster nozzle, install push-to-connect fitting
4. Connect silicone tubing from thruster to replica nozzle on load cell
5. Secure tubing to prevent sagging/pulling on load cell
6. Verify load cell reads zero with thruster off
7. For each thruster:
   - Fire thruster for 10 seconds
   - Record load cell reading
   - Rest 5 seconds
   - Repeat 25 times
8. Repeat for all 8 thrusters twice

#### The Breakthrough: Hardware Finally Works

**Before In-Situ Calibration**:
- MPC controller completely unstable
- Satellite spins unpredictably
- Cannot hold even a single waypoint
- **Control system does not work at all**

**After In-Situ Calibration**:
- MPC controller stable on first test
- Satellite holds waypoints with <5cm error
- Successful shape-following missions
- **Control system works reliably**

#### Why Accurate Calibration is Non-Negotiable for MPC

**MPC Prediction Horizon** (N = 12 steps × 0.06s = 0.72s future):
```
MPC predicts: "If I fire thruster 3 at for 3 steps, satellite will move X and rotate Y"
```

**With Inaccurate Model** (Thrust = 0.85N assumed, actually 0.92N = 8% error):
```
After 0.9s:
- Predicted position: (1.00m, 0.50m)
- Actual position: (1.08m, 0.54m)  ← 8% error propagated
- Position error: 9.4cm
```

**With Accurate Model** (Thrust = 0.92N, correct):
```
After 0.9s:
- Predicted position: (1.00m, 0.50m)
- Actual position: (1.02m, 0.51m)  ← Only sensor noise
- Position error: 2.2cm
```

**MPC Requires Accurate Models**:
- **Model-based** means predictions must match reality
- Errors compound over prediction horizon
- 10% thrust error → 10% position error → wrong control → instability
- **No amount of tuning can fix bad model**

#### Lessons for Model-Based Control

1. **Measure in flight configuration**

2. **Individual component characterization**: Don't assume components are identical
   - The 8 "identical" solenoid valves varied in performance
   - MPC performance improved dramatically when accounting for individual differences

3. **Spend time on system calibration**:
   - Thruster bench: 2 hours to design, with total cost of $30 for components
   - Result: Project went from non-functional to functional
   - **Best time investment in entire project**

4. **Prediction horizon**:
   - Longer MPC horizon → more stringent accuracy requirement
   - Shorter horizon might give less optimal control but is much more forgiving, better suited for non-perfect environments like this lab

**Recommendation**: For any model-based controller (MPC, LQR, etc.), **invest heavily in accurate system identification**. Spend time on calibration before tuning control gains. Bad model + good controller = failure. Good model + mediocre controller = success.

---

## Software Control Algorithm Development

### MPC Formulation Evolution

The MPC formulation went through several iterations before arriving at the final working implementation. This section documents the mathematical evolution and design decisions.

#### State Space Representation

**Final State Vector** (6 states):
```
x = [x_pos, y_pos, theta, x_vel, y_vel, omega]^T

Where:
- x_pos, y_pos: Position in workspace (meters)
- theta: Orientation angle (radians)
- x_vel, y_vel: Linear velocity (m/s)
- omega: Angular velocity (rad/s)
```

**Control Input Vector** (8 binary inputs):
```
u = [u1, u2, u3, u4, u5, u6, u7, u8]^T

Where:
- ui ∈ {0, 1}: Binary on/off for thruster i
- Mixed-Integer Programming (MIP) problem
```

**Why Binary Thrusters?**:
- **Hardware constraint**: Solenoid valves are on/off (no proportional control)
- **Cost**: Proportional valves $200+ each vs. binary solenoid ~$12
- **Complexity**: Binary control simpler mechanically and more reliable
- **MPC challenge**: Binary variables → MIP (harder than continuous optimization)

#### Dynamics Model: Linearization Strategy

**True Nonlinear Dynamics**:
```
ẋ = v_x cos(θ) - v_y sin(θ)
ẏ = v_x sin(θ) + v_y cos(θ)
θ̇ = ω
v̇_x = (1/m) Σ F_i cos(α_i + θ)
v̇_y = (1/m) Σ F_i sin(α_i + θ)
ω̇ = (1/I) Σ F_i × r_i

Where:
- m: Satellite mass (23kg)
- I: Moment of inertia (0.32 kg⋅m²)
- F_i: Thrust force from thruster i
- α_i: Thruster mounting angle
- r_i: Moment arm for thruster i
```

**Linearization Approach**:

MPC requires linear dynamics for efficient solution. We linearize around **current state** each time step (successive linearization).

**Iteration 1**: Global Linearization (FAILED)
- Linearize around θ = 0
- Assumption: Small angle deviations
- **Problem**: Breaks down for large rotations (> 30°)
- **Result**: MPC unstable during turns

**Iteration 2**: Local Linearization (IMPROVED)
- Linearize around current state (x_k, u_k) each time step
- Compute Jacobian A_k, B_k at current state
- **Problem**: Linearization error for multi-step prediction
- **Result**: Stable but suboptimal

**Iteration 3**: Successive Linearization with Warm Start (FINAL)
- Linearize around current state
- Use previous solution as warm start for next solve
- Update linearization each time step (receding horizon)
- **Result**: Stable and near-optimal

**Linearized Dynamics** (computed each time step):
```
x_{k+1} = A_k x_k + B_k u_k

Where:
A_k = I + Δt × ∂f/∂x |_{x_k, u_k}
B_k = Δt × ∂f/∂u |_{x_k, u_k}

Δt = CONTROL_DT
```

#### Cost Function Evolution

**Objective**: Minimize tracking error and control effort

**Iteration 1**: Quadratic Cost (Standard)
```
J = Σ (x_k - x_ref)^T Q (x_k - x_ref) + u_k^T R u_k
```
- **Problem**: Binary u_k makes this nonlinear in binary variables
- Gurobi requires quadratic objective in **continuous** variables

**Iteration 2**: Linearized Cost (Workaround)
```
J = Σ ||x_k - x_ref||_Q² + Σ r_i u_i

Where:
- ||x - x_ref||_Q²: Quadratic state error weighted by Q matrix
- r_i u_i: Linear control cost (works with binary u_i)
```
- **Problem**: Doesn't penalize thruster switching (chattering)

**Iteration 3**: Cost with Switching Penalty (FINAL)
```
J = Σ_{k=0}^{N-1} [ (x_k - x_ref)^T Q (x_k - x_ref) + Σ_i (r_thrust u_{i,k} + r_switch |u_{i,k} - u_{i,k-1}|) ]

Where:
Q = diag([Q_pos, Q_pos, Q_angle, Q_vel, Q_vel, Q_omega])
r_thrust: Cost per thruster activation
r_switch: Cost per thruster state change (on→off or off→on)
```

**Cost Weight Tuning** (Final Values):
```python
Q_POSITION = 1000.0       # Position error penalty (m⁻²)
Q_VELOCITY = 1750.0       # Velocity error penalty (s²/m²)
Q_ANGLE = 1000.0          # Angle error penalty (rad⁻²)
Q_ANGULAR_VELOCITY = 1500.0  # Angular velocity penalty (s²/rad²)
R_THRUST = 1.0            # Thrust usage cost
R_SWITCH = 0.0            # Switching cost (disabled in final tuning)
```

**Tuning Process**:
1. Start with Q_position = 1, all others = 0 → learns to reach position
2. Add Q_velocity → learns to arrive smoothly
3. Add Q_angle → learns to orient correctly
4. Add R_thrust → learns fuel efficiency
5. Add R_switch → eliminates thruster chattering
6. Iterate to balance performance vs. fuel usage

#### Constraints

**State Constraints**:
```python
# Position bounds (6m × 6m workspace)
-3.0 ≤ x_pos ≤ 3.0
-3.0 ≤ y_pos ≤ 3.0

# Velocity limits (safety)
-0.25 ≤ v_x ≤ 0.25  (m/s)
-0.25 ≤ v_y ≤ 0.25
-π/2 ≤ ω ≤ π/2      (rad/s)

# Angle: unconstrained (can spin freely)
```

**Control Constraints**:
```python
u_i ∈ {0, 1}  ∀ i ∈ [1, 8]  # Binary thruster on/off
```

#### Horizon Length Selection

**Key Parameter**: `MPC_PREDICTION_HORIZON = N`

**Trade-offs**:
- **Longer horizon** (N large):
  - (+) Better long-term planning
  - (+) Smoother trajectories
  - (−) More decision variables → longer solve time
  - (−) Linearization error accumulates

- **Shorter horizon** (N small):
  - (+) Faster solves
  - (+) More accurate linearization (less future prediction)
  - (+) Better suited for non-perfect environment like labs
  - (−) Myopic behavior
  - (−) Poor anticipation of future obstacles

**Tested Values**:
| N | Solve Time | Performance | Selected? |
|---|---|---|---|
| 5 | 3-8ms | Poor | No |
| 10 | 5-20ms | Adequate | No |
| 12 | 5-40ms | Good | **Yes** |
| 20 | 10-50ms | Adequate | No, does not do well with unpredicted external forces |
| 25 | 20-60ms | Poor | No (exceeds deadline) |

**Selected**: N = 12 (0.72 seconds lookahead)
- Adequate performance
- Meets real-time deadline (<50ms)
- Good balance

**Control Horizon**: `MPC_CONTROL_HORIZON = M = 12`
- Only first M steps have independent control
- Last (N - M) steps use terminal constraint or repeated control

#### Gurobi Solver Configuration: The Performance Breakthrough

This was the **second critical software breakthrough** (after accurate thruster calibration).

**The Problem**: Solver Timing Violations

**Initial Performance** (Default Gurobi settings):
- Solve time: 50-180ms
- Time budget: 50ms (MPC_SOLVER_TIME_LIMIT)
- **Result**: Multiple solves exceeded deadline so control intervals had to be extended

**Root Cause**: Didn't understand the solver parameters

I could formulate the MPC problem correctly mathematically, but didn't understand **how Gurobi solves MIP problems** or **what parameters control the solve strategy**.

**Key Realization**: **MPC doesn't need optimal solutions, just good feasible solutions quickly**

**The MPC Advantage**:
- Receding horizon: Next time step replans anyway
- 1% suboptimal solution arriving in 10ms >> optimal solution arriving in 60ms
- **Speed more important than optimality** for real-time control

**Solver Parameter Tuning** (The Breakthrough):

```python
# Real-time MPC settings (FINAL)
self.model.setParam("MIPGap", 1e-2)              # 1% optimality gap
self.model.setParam("MIPFocus", 1)               # Focus on finding solutions
self.model.setParam("Heuristics", 0.01)          # Minimal heuristics (1% time)
self.model.setParam("Cuts", 1)                   # Conservative cuts
self.model.setParam("Presolve", 2)               # Aggressive presolve
self.model.setParam("Threads", 1)                # Single-threaded
self.model.setParam("ImproveStartTime", 0.6*TimeLimit)  # Improve after 60% time
self.model.setParam("TimeLimit", 0.050)          # Hard 50ms deadline
```

**Detailed Parameter Analysis**:

**1. MIPGap = 1e-2 (THE MOST CRITICAL SETTING)**

What it does:
- Gurobi stops when: (Upper Bound - Lower Bound) / Upper Bound ≤ MIPGap
- Upper bound: Best feasible solution found
- Lower bound: Proven lower limit on objective value
- **1% gap = solution within 1% of proven optimal**

Why it helps:
- Default MIPGap = 1e-4 (0.01%) → Gurobi proves very tight optimality → slow
- Relaxed to 1e-2 (1%) → Gurobi stops much earlier → fast
- For MPC: 1% suboptimal is acceptable in practice

Performance impact:
- **Before** (MIPGap = 1e-4): Mean solve time 85ms
- **After** (MIPGap = 1e-2): Mean solve time 5ms

**Selected**: 1e-2 (1%) - best balance

**2. MIPFocus = 1 (Focus on Feasibility)**

What it does:
- Controls Gurobi's search strategy
- Options:
  - 0 (Default): Balanced
  - 1: Emphasize **finding feasible solutions**
  - 2: Emphasize **proving optimality**
  - 3: Focus on **improving best bound**

Why it helps:
- MIPFocus=1 tells Gurobi: "Find solutions fast, don't spend time proving they're optimal"
- Complements MIPGap setting
- Gurobi adjusts heuristics and branching to find solutions quickly

**3. Heuristics = 0.01 (Minimal Heuristics)**

What it does:
- Controls time spent on heuristic algorithms (fast approximations)
- Range: 0.0 (none) to 1.0 (lots)
- 0.01 = spend only 1% of time on heuristics

Why it helps:
- For small problems (N=12, 8 thrusters = 96 binary variables), heuristics have overhead
- Branch-and-cut is more efficient for structured MPC problems
- Heuristics more valuable for large, unstructured problems (1000+ variables)

**4. Cuts = 1 (Conservative Cuts)**

What it does:
- Controls cutting plane generation (linear inequalities that tighten LP relaxation)
- Options:
  - 0: No cuts
  - 1: Conservative (few cuts)
  - 2: Moderate (default)
  - 3: Aggressive (many cuts)

Why it helps:
- Cuts help prune branches, but generation takes time
- Conservative cuts: Fast generation, reasonable pruning
- For real-time: Prefer fast solve over tight bounds

Performance impact:
- Cuts=2 (default): Slightly slower
- Cuts=1: Marginally faster (5%)
- Cuts=0: Faster solve, worse solution quality

**5. Presolve = 2 (Aggressive Presolve)**

What it does:
- Preprocessing before solving (removes redundant variables/constraints)
- Options:
  - 0: No presolve
  - 1: Conservative
  - 2: Aggressive

Why it helps:
- MPC formulation has redundant constraints (dynamics linearization creates dependencies)
- Aggressive presolve removes redundancy → smaller problem → faster solve

**6. Threads = 1 (Single-Threaded)**

What it does:
- Controls number of parallel threads
- Default: -1 (auto, often 4-8 threads)

Why it helps:
- Small problems (96 binary variables) solve faster single-threaded
- Multi-threading overhead:
  - Thread creation/synchronization
  - Cache contention between threads
  - Load balancing overhead

**For large problems (1000+ variables)**: Multi-threading helps
**For small MPC problems**: Single-threaded is faster

**7. ImproveStartTime = 0.6 × TimeLimit (Timing Strategy)**

What it does:
- First 60% of time: Focus on finding feasible solutions
- Last 40% of time: Improve solution quality

Why it helps:
- Ensures Gurobi finds **some** solution quickly
- Without this: Might spend all 50ms on one hard branch, return nothing
- With this: Find solution in first 30ms, polish it for last 20ms

**8. TimeLimit = 0.050 (Hard Deadline)**

What it does:
- Gurobi stops **immediately** when time limit reached
- Returns best solution found (or error if no solution)

Why it helps:
- Real-time guarantee: Solver never blocks beyond deadline
- MPC can handle suboptimal solution; cannot handle missed deadline

**Lesson**: **Learn your solver's parameters**. The difference between default Gurobi and tuned Gurobi was the difference between 180ms control intervals and 60ms control intervals. Mathematical formulation is only half the battle; solver configuration is equally important for real-time applications.

#### Warm Start Strategy

**Concept**: Use previous solution as starting point for next solve

**Implementation**:
```python
# After solve at time k:
u_prev = u_optimal[k]

# At time k+1:
# Shift previous solution as initial guess
u_init = [u_prev[1], u_prev[2], ..., u_prev[N-1], u_prev[N-1]]
model.setAttr("Start", u_vars, u_init)
```

**Why it helps**:
- Successive MPC problems are similar (small state change)
- Previous solution likely close to new optimal
- Gurobi starts branch-and-bound from good initial point → faster convergence

**Caveat**: Large disturbances or target changes → warm start less helpful

### Software Architecture Decisions

#### Modular Configuration System

**Problem**: Parameters scattered across code, hard to tune

**Solution**: Centralized `config/` package with type-safe dataclasses

**Structure**:
```
config/
├── physics.py       # Mass, inertia, thruster forces
├── timing.py        # Control rates, stabilization times
├── mpc_params.py    # Horizons, weights, solver settings
├── constants.py     # Ports, paths, UI settings
├── mission_state.py # Runtime mission parameters
└── obstacles.py     # Obstacle definitions
```

**Benefits**:
1. **Single source of truth**: All parameters in one place
2. **Type safety**: Dataclasses catch type errors at import
3. **Documentation**: Parameters documented with units
4. **Validation**: Automatic sanity checking
5. **Easy tuning**: Change one file, entire system updates

**Example**:
```python
# config/mpc_params.py
MPC_PREDICTION_HORIZON = 12  # Time steps (0.72s lookahead)
MPC_CONTROL_HORIZON = 12     # Control steps
Q_POSITION = 1000.0          # Position error penalty (m⁻²)

# Anywhere in code:
from config import SatelliteConfig
N = SatelliteConfig.MPC_PREDICTION_HORIZON
```

**Lesson**: **Invest in configuration infrastructure early**. Tuning MPC requires changing many parameters frequently. Centralized config paid off immediately.

#### Simulation-Hardware Parity

**Design Principle**: **Same MPC code for simulation and hardware**

**Implementation**:
- `mpc.py`: Core MPC solver (used by both)
- `model.py`: Satellite physics (used by both)
- `simulation.py`: Physics-based simulation + MPC
- `real.py`: Hardware interface + MPC (same MPC code)

**Benefits**:
1. **Validation**: Simulation predicts hardware behavior
2. **Safety**: Test in simulation before hardware
3. **Debugging**: If simulation works but hardware doesn't → hardware issue (not control algorithm)
4. **Development speed**: Develop control without hardware access

**Critical Insight**: When hardware failed initially, **simulation worked perfectly**. This immediately indicated: MPC algorithm is correct, problem is in hardware characterization (thrust calibration) or communication (latency).

**Without simulation-hardware parity**: Would have suspected MPC algorithm bug, wasted time debugging correct code.

**Lesson**: **Build high-fidelity simulation before hardware**. Simulation is not just for testing; it's a **debugging tool** that isolates software vs. hardware issues.

---

## Critical Breakthroughs (The Big Three)

Three breakthroughs were **absolutely essential** for system functionality. Without any one of them, the system would not work.

### Breakthrough 1: In-Situ Thruster Calibration

**Problem**: Hardware completely unstable despite perfect simulation

**Root Cause**: Thrust model inaccuracy

**Solution**: In-situ calibration bench measuring thrusters in flight configuration

**Impact**:
- Before: System unable to stabilize and reach targets
- After: System stable and stabilizes on targets in first try without oscillations
- **Enabled**: Entire project (without this, system doesn't work at all)

### Breakthrough 2: ESP-NOW Communication Protocol

**Problem**: WiFi latency violated MPC assumptions, caused instability

**Root Cause**: Standard WiFi protocol overhead incompatible with MPC timing requirements

**Solution**: Switched to ESP-NOW (ultra-low-latency peer-to-peer protocol)

**Impact**:
- Before: MPC predictions stale by time commands arrive → unstable
- After: Commands arrive within 10ms → predictions valid → stable
- **Enabled**: Closed-loop hardware control

### Breakthrough 3: Gurobi MIPGap Tuning

**Problem**: MPC solver too slow

**Root Cause**: Default Gurobi settings prioritize optimality over speed

**Solution**: Relaxed MIPGap to 1e-2 (1%), focused solver on finding feasible solutions fast

**Impact**:
- Before: 180ms control intervals → less precise control → instability
- After: 60ms control intervals → precise control → stable
- **Enabled**: Real-time MPC in hardware

### Why These Three Together

**All three required**:
1. **Accurate model** (thrust calibration) → MPC predictions valid
2. **Low latency** (ESP-NOW) → Predictions still valid when commands arrive
3. **Fast solver** (Gurobi tuning) → Commands computed in shorter amount of time for more precise control

**Without any one**:
- No thrust calibration → Predictions wrong → Control fails
- No ESP-NOW → Commands arrive too late → Control fails
- No solver tuning → Command intervals larger → less precise control

**Sequential Discovery**:
- Fixed communication first (ESP-NOW) → Still unstable
- Fixed thrust calibration next → Much better, but long control intervals
- Fixed solver tuning last → Fully stable system with more precise control

**Lesson**: **Complex systems require multiple components working correctly**. Debugging is process of elimination, fixing bottlenecks sequentially until system works.

---

## Recommendations for Future Work

Based on lessons learned, here are recommendations for future researchers extending this work.

### Hardware Improvements

**1. Proportional Thrusters**
- **Current**: Binary on/off solenoids
- **Proposed**: Proportional valves with variable flow rate
- **Benefits**:
  - Finer control authority
  - Reduced chattering
  - Better fuel efficiency
- **Challenges**:
  - Cost more and might be less reliable
  - MPC formulation changes (continuous control instead of binary)
  - Characterization more complex

**2. Onboard MPC Computation**
- **Current**: Ground-station MPC, wireless command uplink
- **Proposed**: Embedded MPC on satellite microcontroller
- **Benefits**:
  - No communication latency
  - More realistic for actual satellite
  - Simpler system architecture
- **Challenges**:
  - Embedded solver needed (Gurobi won't run on ESP32)
  - Limited computational power (ESP32 much slower than laptop)
  - May need simpler MPC formulation (shorter horizon)

**3. Redundant Thrusters**
- **Current**: 8 thrusters, no redundancy
- **Proposed**: 12 thrusters (50% redundancy)
- **Benefits**:
  - Fault tolerance (can lose 4 thrusters and remain controllable)
  - Over-actuated system enables fuel optimization
- **Challenges**:
  - Increased complexity
  - MPC problem size larger (12 binary variables vs. 8)
  - More weight, more cost

**4. Improved Air Bearing Design**
- **Current**: 3 air bearings, manual balancing
- **Proposed**: Active balancing system
- **Implementation**: Motorized air bearing positioning
- **Benefits**:
  - Automatic COM correction
  - Adaptive to payload changes
  - Easier to balance
- **Challenges**:
  - Complexity, cost, weight

### Software/Control Improvements

**1. Nonlinear MPC**
- **Current**: Successive linearization
- **Proposed**: Full nonlinear optimization
- **Benefits**:
  - More accurate predictions (no linearization error)
  - Better performance for large rotations
- **Challenges**:
  - Nonlinear MIP extremely hard to solve
  - Unlikely to meet real-time deadline with current solvers
  - Requires advanced solver

**2. Multi-Agent Coordination**
- **Current**: Single satellite
- **Proposed**: Multiple satellites with coordinated MPC
- **Implementation**: Distributed MPC with communication
- **Benefits**:
  - Formation flying
  - Cooperative missions
  - Collision avoidance
- **Challenges**:
  - Communication between satellites
  - Coupled optimization problem
  - Scalability

---

## Conclusion

This project successfully demonstrated **Model Predictive Control for satellite thruster control** using a hardware air-bearing testbed. The journey from concept to functional system required overcoming significant challenges in hardware characterization, communication latency, and real-time optimization.

**Three critical breakthroughs** enabled system functionality:
1. In-situ thruster calibration for accurate model
2. ESP-NOW communication for low latency
3. Gurobi solver tuning for real-time performance

**Key Lessons**:
- **Model accuracy is non-negotiable** for model-based control
- **Communication latency is a hard constraint** for distributed MPC
- **Solver configuration is as important as mathematical formulation** for real-time optimization
- **Build high-fidelity simulation first** before hardware
- **Document failures and iterations** (most learning comes from what didn't work)

**Final Recommendation**: If you're building a similar system, **read this document first**. Learn from my failures. The breakthroughs documented here represent months of debugging—understanding them will save you significant time and effort.

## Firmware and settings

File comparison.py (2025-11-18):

#!/usr/bin/env python3
"""
Real Test vs Simulation Comparison Visualization

Side-by-side comparison visualization between real test data and simulation data,
using the same animation style as visualize.py.

Features:
- Interactive file selection for real test and simulation data
- Side-by-side animation with info panel
- Unified drawing methods matching visualize.py style
- High-quality MP4 animation generation
- Comprehensive comparison metrics display
- Real-time playback with proper timing
"""

import os
import sys

import matplotlib
import numpy as np

matplotlib.use("Agg")  # Use non-interactive backend
import csv
import platform
import shutil
from datetime import datetime
from pathlib import Path
from typing import Any, List, Optional

import matplotlib.pyplot as plt
from cycler import cycler
from matplotlib.animation import FuncAnimation, writers
from matplotlib.patches import Circle

from config import SatelliteConfig

# Configure ffmpeg path with Config-first logic, then safe fallbacks
try:
    if getattr(SatelliteConfig, "FFMPEG_PATH", None):
        plt.rcParams["animation.ffmpeg_path"] = SatelliteConfig.FFMPEG_PATH
    else:
        # If ffmpeg already in PATH, do nothing
        if shutil.which("ffmpeg") is None:
            if platform.system() == "Darwin":
                brew_ffmpeg = "/opt/homebrew/bin/ffmpeg"
                if os.path.exists(brew_ffmpeg):
                    plt.rcParams["animation.ffmpeg_path"] = brew_ffmpeg
except Exception:
    pass

import warnings

warnings.filterwarnings("ignore")

# Set matplotlib color scheme
plt.rcParams["axes.prop_cycle"] = cycler(
    color=[
        "#1f77b4",
        "#ff7f0e",
        "#2ca02c",
        "#d62728",
        "#9467bd",
        "#8c564b",
        "#e377c2",
        "#7f7f7f",
    ]
)

# Consistent plot styling
plt.rcParams.update(
    {
        "axes.titlesize": 14,
        "axes.titleweight": "normal",
        "axes.labelsize": 12,
        "legend.fontsize": 10,
        "font.family": "DejaVu Sans",
    }
)


class ComparisonVisualizationGenerator:
    """Comparison visualization generator for real test vs simulation data."""

    def __init__(self, real_csv_path: str, sim_csv_path: str) -> None:
        """Initialize the comparison visualization generator.

        Args:
            real_csv_path: Path to real test CSV file
            sim_csv_path: Path to simulation CSV file
        """
        self.real_csv_path = Path(real_csv_path)
        self.sim_csv_path = Path(sim_csv_path)

        # Create output directory
        timestamp = datetime.now().strftime("%Y%m%d_%H%M%S")
        self.output_dir = Path("Data/Comparison") / f"comparison_{timestamp}"
        self.output_dir.mkdir(parents=True, exist_ok=True)

        print(f"Output directory: {self.output_dir}")

        # Animation parameters (set defaults first)
        self.fps = 30
        self.speedup_factor = 1
        self.dt = 0.1

        # Load data (this will update fps and dt based on actual data)
        self.real_data = None
        self.sim_data = None
        self._real_rows = []
        self._sim_rows = []

        self.load_data()

        # Satellite configuration
        self.satellite_size = SatelliteConfig.SATELLITE_SIZE
        self.thrusters = {}
        for thruster_id, pos in SatelliteConfig.THRUSTER_POSITIONS.items():
            self.thrusters[thruster_id] = pos

        # Figure references
        self.fig = None
        self.ax_real = None
        self.ax_sim = None
        self.ax_info = None

        print(f" Loaded real test data: {len(self._real_rows)} rows")
        print(f" Loaded simulation data: {len(self._sim_rows)} rows")

    def load_data(self) -> None:
        """Load both real test and simulation CSV data."""
        print(f"\nLoading real test data from: {self.real_csv_path}")
        self._real_rows = []
        with open(self.real_csv_path, "r") as f:
            reader = csv.DictReader(f)
            for row in reader:
                self._real_rows.append(row)

        print(f"Loading simulation data from: {self.sim_csv_path}")
        self._sim_rows = []
        with open(self.sim_csv_path, "r") as f:
            reader = csv.DictReader(f)
            for row in reader:
                self._sim_rows.append(row)

        # Detect timestep from first few rows
        if len(self._real_rows) > 1:
            try:
                t1 = float(
                    self._real_rows[0].get(
                        "Control_Time", self._real_rows[0].get("time", 0)
                    )
                )
                t2 = float(
                    self._real_rows[1].get(
                        "Control_Time", self._real_rows[1].get("time", 0)
                    )
                )
                self.dt = abs(t2 - t1)
                if self.dt > 0:
                    self.fps = min(
                        max(int(1.0 / self.dt), 10), 60
                    )  # Clamp between 10-60
                else:
                    self.dt = 0.1
                    self.fps = 30
                print(f"Detected timestep: {self.dt:.3f}s, FPS: {self.fps}")
            except Exception:
                self.dt = 0.1
                self.fps = 30
                print(f"Using default timestep: {self.dt}s, FPS: {self.fps}")
        else:
            self.dt = 0.1
            self.fps = 30
            print(f"Using default timestep: {self.dt}s, FPS: {self.fps}")

    def parse_command_vector(self, command_str: str) -> np.ndarray:
        """Parse command vector string to numpy array.

        Args:
            command_str: String representation of command vector

        Returns:
            Numpy array of thruster commands
        """
        if not command_str or command_str == "None":
            return np.zeros(8)

        try:
            # Remove brackets and quotes, split by comma
            clean_str = command_str.strip("[]\"'")
            values = [float(x.strip()) for x in clean_str.split(",")]
            if len(values) == 8:
                return np.array(values)
            else:
                return np.zeros(8)
        except Exception as e:
            # Print parsing error for debugging
            print(f"Warning: Could not parse command vector: '{command_str}' - {e}")
            return np.zeros(8)

    def get_active_thrusters(self, command_vector: np.ndarray) -> list:
        """Get list of active thruster IDs from command vector.

        Args:
            command_vector: Array of thruster commands

        Returns:
            List of active thruster IDs (1-8)
        """
        return [i + 1 for i, cmd in enumerate(command_vector) if cmd > 0.5]

    def setup_plot(self) -> None:
        """Initialize matplotlib figure and axes."""
        self.fig = plt.figure(figsize=(20, 9))
        self.fig.suptitle(
            "Real Test vs Simulation Comparison", fontsize=16, fontweight="bold"
        )

        # Create subplots: Real Test | Simulation | Info Panel
        self.ax_real = plt.subplot2grid((1, 5), (0, 0), colspan=2)
        self.ax_sim = plt.subplot2grid((1, 5), (0, 2), colspan=2)
        self.ax_info = plt.subplot2grid((1, 5), (0, 4))

        # Configure info panel
        self.ax_info.set_xlim(0, 1)
        self.ax_info.set_ylim(0, 1)
        self.ax_info.axis("off")

        plt.tight_layout()

    def draw_satellite(
        self,
        ax: Any,
        x: float,
        y: float,
        yaw: float,
        active_thrusters: list,
        color: str = "blue",
    ) -> None:
        """Draw satellite at given position and orientation (matching Visualize.py).

        Args:
            ax: Matplotlib axis to draw on
            x, y: Satellite position
            yaw: Satellite orientation (radians)
            active_thrusters: List of active thruster IDs
            color: Satellite body color
        """
        # Rotation matrix
        cos_yaw = np.cos(yaw)
        sin_yaw = np.sin(yaw)
        rotation_matrix = np.array([[cos_yaw, -sin_yaw], [sin_yaw, cos_yaw]])

        body_corners = np.array(
            [
                [-self.satellite_size / 2, -self.satellite_size / 2],
                [self.satellite_size / 2, -self.satellite_size / 2],
                [self.satellite_size / 2, self.satellite_size / 2],
                [-self.satellite_size / 2, self.satellite_size / 2],
                [-self.satellite_size / 2, -self.satellite_size / 2],
            ]
        )

        # Rotate and translate body
        rotated_body = body_corners @ rotation_matrix.T + np.array([x, y])
        ax.plot(
            rotated_body[:, 0],
            rotated_body[:, 1],
            color=color,
            linewidth=3,
            label="Satellite",
            zorder=15,
        )

        # Fill the satellite body
        ax.fill(
            rotated_body[:, 0], rotated_body[:, 1], color=color, alpha=0.3, zorder=14
        )

        # Draw thrusters
        for thruster_id, (tx, ty) in self.thrusters.items():
            # Rotate thruster position
            thruster_pos = np.array([tx, ty]) @ rotation_matrix.T
            thruster_x = x + thruster_pos[0]
            thruster_y = y + thruster_pos[1]

            # Color and size based on activity
            if thruster_id in active_thrusters:
                t_color = "red"
                size = 80
                marker = "o"
                alpha = 1.0
            else:
                t_color = "gray"
                size = 40
                marker = "s"
                alpha = 0.5

            ax.scatter(
                thruster_x,
                thruster_y,
                c=t_color,
                s=size,
                marker=marker,
                alpha=alpha,
                edgecolors="black",
                linewidth=1,
                zorder=16,
            )

        # Draw orientation arrow
        arrow_length = self.satellite_size * 0.8
        arrow_end_x = x + arrow_length * cos_yaw
        arrow_end_y = y + arrow_length * sin_yaw
        ax.arrow(
            x,
            y,
            arrow_end_x - x,
            arrow_end_y - y,
            head_width=0.08,
            head_length=0.08,
            fc="green",
            ec="green",
            linewidth=2,
            alpha=0.8,
            zorder=17,
        )

    def draw_target(
        self, ax: Any, target_x: float, target_y: float, target_yaw: float
    ) -> None:
        """Draw target position and orientation (matching Visualize.py).

        Args:
            ax: Matplotlib axis to draw on
            target_x, target_y: Target position
            target_yaw: Target orientation (radians)
        """
        ax.scatter(
            target_x,
            target_y,
            c="red",
            s=200,
            marker="x",
            linewidth=4,
            label="Target",
            zorder=10,
        )

        # Target circle
        circle = Circle(
            (target_x, target_y), 0.05, color="red", fill=False, linewidth=2, alpha=0.7
        )
        ax.add_patch(circle)

        # Target orientation arrow
        arrow_length = self.satellite_size * 0.6
        arrow_end_x = target_x + arrow_length * np.cos(target_yaw)
        arrow_end_y = target_y + arrow_length * np.sin(target_yaw)
        ax.arrow(
            target_x,
            target_y,
            arrow_end_x - target_x,
            arrow_end_y - target_y,
            head_width=0.06,
            head_length=0.06,
            fc="red",
            ec="red",
            alpha=0.8,
            linewidth=2,
            zorder=9,
        )

    def draw_trajectory(
        self, ax: Any, trajectory_x: list, trajectory_y: list, color: str
    ) -> None:
        """Draw satellite trajectory (matching Visualize.py).

        Args:
            ax: Matplotlib axis to draw on
            trajectory_x, trajectory_y: Lists of trajectory points
            color: Trajectory color
        """
        if len(trajectory_x) > 1:
            ax.plot(
                trajectory_x,
                trajectory_y,
                color=color,
                linewidth=2,
                alpha=0.8,
                linestyle="-",
                label="Trajectory",
                zorder=5,
            )

    def update_info_panel(self, frame: int) -> None:
        """Update information panel with current data (matching Visualize.py style).

        Args:
            frame: Current frame number
        """
        # If axes haven't been created yet, skip updating info panel
        if self.ax_info is None:
            return

        self.ax_info.clear()
        self.ax_info.set_xlim(0, 1)
        self.ax_info.set_ylim(0, 1)
        self.ax_info.axis("off")
        self.ax_info.set_title("Comparison Info", fontsize=12, weight="bold")

        # Bound frame to valid range
        frame = min(frame, len(self._real_rows) - 1, len(self._sim_rows) - 1)

        # Get current data
        real_row = self._real_rows[frame]
        sim_row = self._sim_rows[frame]

        # Parse real test data
        real_x = float(real_row["Current_X"])
        real_y = float(real_row["Current_Y"])
        real_yaw = float(real_row["Current_Yaw"])
        real_err_x = float(real_row["Error_X"])
        real_err_y = float(real_row["Error_Y"])
        real_err_yaw = float(real_row["Error_Yaw"])
        real_pos_err = np.sqrt(real_err_x**2 + real_err_y**2)
        real_angle_err = abs(np.degrees(real_err_yaw))

        real_cmd = self.parse_command_vector(real_row["Command_Vector"])
        real_active = self.get_active_thrusters(real_cmd)

        # Parse simulation data
        sim_x = float(sim_row["Current_X"])
        sim_y = float(sim_row["Current_Y"])
        sim_yaw = float(sim_row["Current_Yaw"])
        sim_err_x = float(sim_row["Error_X"])
        sim_err_y = float(sim_row["Error_Y"])
        sim_err_yaw = float(sim_row["Error_Yaw"])
        sim_pos_err = np.sqrt(sim_err_x**2 + sim_err_y**2)
        sim_angle_err = abs(np.degrees(sim_err_yaw))

        sim_cmd = self.parse_command_vector(sim_row["Command_Vector"])
        sim_active = self.get_active_thrusters(sim_cmd)

        # Get time
        real_time = float(real_row.get("Control_Time", frame * self.dt))

        # Information text - matching Visualize.py style
        info_text = [
            "COMPARISON",
            "=" * 25,
            f"Frame: {frame}/{min(len(self._real_rows), len(self._sim_rows)) - 1}",
            f"Time: {real_time:.2f}s",
            "",
            "REAL TEST:",
            f"Pos: ({real_x:.3f}, {real_y:.3f})",
            f"Yaw: {np.degrees(real_yaw):.1f}°",
            f"Pos Error: {real_pos_err:.3f} m",
            f"Angle Error: {real_angle_err:.1f}°",
            f"Thrusters: {real_active}",
            f"Count: {len(real_active)}/8",
            "",
            "SIMULATION:",
            f"Pos: ({sim_x:.3f}, {sim_y:.3f})",
            f"Yaw: {np.degrees(sim_yaw):.1f}°",
            f"Pos Error: {sim_pos_err:.3f} m",
            f"Angle Error: {sim_angle_err:.1f}°",
            f"Thrusters: {sim_active}",
            f"Count: {len(sim_active)}/8",
            "",
            "DIFFERENCE:",
            f"ΔPos Error: {abs(real_pos_err - sim_pos_err):.3f} m",
            f"ΔAngle Error: {abs(real_angle_err - sim_angle_err):.1f}°",
            f"ΔThrusters: {abs(len(real_active) - len(sim_active))}",
        ]

        # Display text - matching Visualize.py style
        y_pos = 0.95
        for line in info_text:
            if line.startswith("="):
                weight, size = "normal", 9
            elif line.isupper() and line.endswith(":"):
                weight, size = "bold", 10
            elif line.startswith(("Frame:", "Time:", "COMPARISON")):
                weight, size = "bold", 11
            else:
                weight, size = "normal", 9

            if not line:
                y_pos -= 0.02
                continue

            self.ax_info.text(
                0.05,
                y_pos,
                line,
                fontsize=size,
                weight=weight,
                verticalalignment="top",
                fontfamily="monospace",
            )
            y_pos -= 0.035

    def animate_frame(self, frame: int) -> List[Any]:
        """Animation update function for each frame (matching Visualize.py).

        Args:
            frame: Frame number
        """
        # Ensure axes exist (setup if called directly)
        if self.ax_real is None or self.ax_sim is None or self.ax_info is None:
            # Lazily initialize the plot if missing
            self.setup_plot()

        # Bound frame to valid range first
        frame = min(frame, len(self._real_rows) - 1, len(self._sim_rows) - 1)

        # Clear both plot axes
        if self.ax_real is not None:
            self.ax_real.clear()
        if self.ax_sim is not None:
            self.ax_sim.clear()

        # Calculate axis limits from all data (cache this if needed for performance)
        try:
            real_x_all = [float(row["Current_X"]) for row in self._real_rows]
            real_y_all = [float(row["Current_Y"]) for row in self._real_rows]
            sim_x_all = [float(row["Current_X"]) for row in self._sim_rows]
            sim_y_all = [float(row["Current_Y"]) for row in self._sim_rows]

            all_x = real_x_all + sim_x_all
            all_y = real_y_all + sim_y_all

            margin = 0.5
            x_min, x_max = min(all_x) - margin, max(all_x) + margin
            y_min, y_max = min(all_y) - margin, max(all_y) + margin
        except Exception:
            # Fallback to default limits
            x_min, x_max = -3, 3
            y_min, y_max = -3, 3

        # Set up both axes (must do each frame after clear)
        for ax, title in [(self.ax_real, "Real Test"), (self.ax_sim, "Simulation")]:
            if ax is None:
                continue
            ax.set_xlim(x_min, x_max)
            ax.set_ylim(y_min, y_max)
            ax.set_aspect("equal")
            ax.grid(True, alpha=0.3)
            ax.set_xlabel("X Position (m)", fontsize=12)
            ax.set_ylabel("Y Position (m)", fontsize=12)
            ax.set_title(title, fontsize=14)

        # Get current data (frame already bounded above)
        real_row = self._real_rows[frame]
        sim_row = self._sim_rows[frame]

        # Parse positions and orientations
        real_x = float(real_row["Current_X"])
        real_y = float(real_row["Current_Y"])
        real_yaw = float(real_row["Current_Yaw"])

        sim_x = float(sim_row["Current_X"])
        sim_y = float(sim_row["Current_Y"])
        sim_yaw = float(sim_row["Current_Yaw"])

        # Parse target (same for both)
        target_x = float(real_row["Target_X"])
        target_y = float(real_row["Target_Y"])
        target_yaw = float(real_row["Target_Yaw"])

        # Parse commands
        real_cmd = self.parse_command_vector(real_row["Command_Vector"])
        real_active = self.get_active_thrusters(real_cmd)

        sim_cmd = self.parse_command_vector(sim_row["Command_Vector"])
        sim_active = self.get_active_thrusters(sim_cmd)

        # Draw targets on both axes
        self.draw_target(self.ax_real, target_x, target_y, target_yaw)
        self.draw_target(self.ax_sim, target_x, target_y, target_yaw)

        # Draw trajectories up to current frame
        real_x_traj = [float(self._real_rows[i]["Current_X"]) for i in range(frame + 1)]
        real_y_traj = [float(self._real_rows[i]["Current_Y"]) for i in range(frame + 1)]
        self.draw_trajectory(self.ax_real, real_x_traj, real_y_traj, "blue")

        sim_x_traj = [float(self._sim_rows[i]["Current_X"]) for i in range(frame + 1)]
        sim_y_traj = [float(self._sim_rows[i]["Current_Y"]) for i in range(frame + 1)]
        self.draw_trajectory(self.ax_sim, sim_x_traj, sim_y_traj, "red")

        # Draw satellites
        self.draw_satellite(self.ax_real, real_x, real_y, real_yaw, real_active, "blue")
        self.draw_satellite(self.ax_sim, sim_x, sim_y, sim_yaw, sim_active, "red")

        # Add legends
        if self.ax_real is not None:
            self.ax_real.legend(loc="upper right", fontsize=9)
        if self.ax_sim is not None:
            self.ax_sim.legend(loc="upper right", fontsize=9)

        # Update info panel
        self.update_info_panel(frame)

        return []

    def generate_comparison_plots(self) -> None:
        """Generate comprehensive comparison plots."""
        print(f"\n{'=' * 70}")
        print("GENERATING COMPARISON PLOTS")
        print(f"{'=' * 70}")

        plot_dir = self.output_dir / "plots"
        plot_dir.mkdir(exist_ok=True)

        print("Creating plots...")
        self._generate_trajectory_plot(plot_dir)
        self._generate_position_error_plot(plot_dir)
        self._generate_angular_error_plot(plot_dir)
        self._generate_velocity_plot(plot_dir)
        # Overlay plot showing real and sim thruster usage on the same axes
        self._generate_thruster_usage_overlay_plot(plot_dir)
        self._generate_mpc_performance_plot(plot_dir)
        self._generate_statistics_table(plot_dir)

        print(f" Plots saved to: {plot_dir}")

    def _generate_trajectory_plot(self, plot_dir: Path) -> None:
        """Generate trajectory comparison plot."""
        print("  - Trajectory comparison...")

        fig, ax = plt.subplots(1, 1, figsize=(12, 10))

        # Extract trajectory data
        real_x = [float(row["Current_X"]) for row in self._real_rows]
        real_y = [float(row["Current_Y"]) for row in self._real_rows]
        sim_x = [float(row["Current_X"]) for row in self._sim_rows]
        sim_y = [float(row["Current_Y"]) for row in self._sim_rows]

        # Plot trajectories
        ax.plot(real_x, real_y, "b-", linewidth=2, label="Real Test", alpha=0.8)
        ax.plot(sim_x, sim_y, "r--", linewidth=2, label="Simulation", alpha=0.8)
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

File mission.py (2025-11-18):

#!/usr/bin/env python3
"""
Unified Mission Module for MPC Satellite Control

Provides unified mission system for both simulation and real testing systems.
Defines common mission types and their configurations.

Mission Types:
1. Waypoint Navigation: Navigate to single or multiple waypoints in sequence
2. Shape Following: Follow moving target along custom shape paths
   - Demo shapes: Circle, Rectangle, Triangle, Hexagon
   - Custom shapes: Load from DXF CAD files

Features:
- Unified interface for both simulation and real hardware
- Automatic mode detection and configuration
- Interactive user input for mission parameters
- Obstacle configuration support
- Mission validation and confirmation
"""

import sys
from pathlib import Path
from typing import Any, Dict, List, Optional, Tuple

import numpy as np

from config import SatelliteConfig

# Add path for optional DXF_Viewer module
sys.path.insert(0, str(Path(__file__).parent / "DXF"))


class MissionManager:
    """Unified mission manager for both simulation and real test systems."""

    def __init__(self, mode: str = "simulation"):
        """Initialize mission manager.

        Args:
            mode: Either "simulation" or "real" to determine behavior
        """
        self.mode = mode.lower()
        if self.mode not in ["simulation", "real"]:
            raise ValueError("Mode must be either 'simulation' or 'real'")

        # Setup mode-specific labels and defaults
        self._setup_mode_labels()

    def _setup_mode_labels(self) -> None:
        """Setup mode-specific labels and defaults."""
        if self.mode == "simulation":
            self.system_name = "SIMULATION"
            self.system_title = "Satellite Control Simulation"
            self.hardware_config = None
        else:  # real
            self.system_name = "REAL HARDWARE TEST"
            self.system_title = "Real Satellite MPC Hardware Test"
            self.hardware_config = {"port": "COM20", "baudrate": 115200}

    def get_user_position(
        self, position_type: str, default_pos: Optional[Tuple[float, float]] = None
    ) -> Tuple[float, float]:
        """Get position input from user with validation.

        Args:
            position_type: Description of position (e.g., "starting", "target")
            default_pos: Default position to use if input fails

        Returns:
            Tuple of (x, y) coordinates
        """
        while True:
            try:
                x_input = input(
                    f"{position_type.title()} X position (meters): "
                ).strip()
                if x_input == "" and default_pos is not None:
                    return default_pos
                x = float(x_input)

                y_input = input(
                    f"{position_type.title()} Y position (meters): "
                ).strip()
                if y_input == "" and default_pos is not None:
                    return default_pos
                y = float(y_input)

                return (x, y)

            except ValueError:
                print("Invalid input. Please enter numeric values.")
                if default_pos is not None:
                    use_default = (
                        input(
                            f"Use default ({default_pos[0]:.2f}, {default_pos[1]:.2f})? (y/n): "
                        )
                        .strip()
                        .lower()
                    )
                    if use_default == "y":
                        return default_pos
            except KeyboardInterrupt:
                print(f"\n{self.system_name} cancelled by user.")
                raise

    def get_user_orientation(
        self, orientation_type: str, default_angle: Optional[float] = None
    ) -> float:
        """Get orientation input from user with validation.

        Args:
            orientation_type: Description of orientation (e.g., "starting", "target")
            default_angle: Default angle in radians

        Returns:
            Angle in radians
        """
        while True:
            try:
                angle_input = input(
                    f"{orientation_type.title()} orientation (degrees): "
                ).strip()
                if angle_input == "" and default_angle is not None:
                    return default_angle
                angle_deg = float(angle_input)
                return np.radians(angle_deg)

            except ValueError:
                print("Invalid input. Please enter a numeric value.")
                if default_angle is not None:
                    default_deg = np.degrees(default_angle)
                    use_default = (
                        input(f"Use default ({default_deg:.1f}°)? (y/n): ")
                        .strip()
                        .lower()
                    )
                    if use_default == "y":
                        return default_angle
            except KeyboardInterrupt:
                print(f"\n{self.system_name} cancelled by user.")
                raise

    def get_user_velocities(
        self,
        default_vx: float = 0.0,
        default_vy: float = 0.0,
        default_omega: float = 0.0,
    ) -> Tuple[float, float, float]:
        """Get initial velocity values from user input.

        Args:
            default_vx: Default X velocity in m/s
            default_vy: Default Y velocity in m/s
            default_omega: Default angular velocity in rad/s

        Returns:
            Tuple of (vx, vy, omega) velocities
        """
        while True:
            try:
                vx_input = input(
                    f"X velocity (m/s, default: {default_vx:.3f}): "
                ).strip()
                vy_input = input(
                    f"Y velocity (m/s, default: {default_vy:.3f}): "
                ).strip()
                omega_input = input(
                    f"Angular velocity (rad/s, default: {default_omega:.3f}): "
                ).strip()

                vx = float(vx_input) if vx_input else default_vx
                vy = float(vy_input) if vy_input else default_vy
                omega = float(omega_input) if omega_input else default_omega

                return (vx, vy, omega)

            except ValueError:
                print("Invalid velocity input. Please enter numeric values.")
            except KeyboardInterrupt:
                print(f"\n{self.system_name} cancelled by user.")
                raise

    def configure_obstacles(self) -> None:
        """Configure obstacles with user input."""
        SatelliteConfig.clear_obstacles()
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

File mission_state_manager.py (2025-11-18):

"""
Mission State Manager for Satellite Control System

Centralized mission logic shared between simulation and real hardware testing.
Provides unified mission state transitions and target calculations for all mission types.

Mission types supported:
1. Waypoint Navigation: Navigate to single or multiple waypoints with rotation control
2. Shape Following: Follow geometric paths (circles, rectangles, triangles, hexagons, DXF imports)

Key features:
- Unified state machine for mission progression
- Position and orientation tolerance checking
- Target calculation and waypoint management
- DXF shape import and path generation
- Mission completion detection
- Eliminates ~800 lines of duplicate code between simulation and real modes
"""

from typing import Callable, List, Optional, Tuple

import numpy as np

from config import SatelliteConfig


class MissionStateManager:
    """
    Manages mission state transitions and target calculations for all mission types.

    This class provides a unified implementation of mission logic for both
    simulation and real hardware control systems.
    """

    def __init__(
        self,
        position_tolerance: float = 0.05,
        angle_tolerance: float = 0.05,
        normalize_angle_func: Optional[Callable[[float], float]] = None,
        angle_difference_func: Optional[Callable[[float, float], float]] = None,
        point_to_line_distance_func: Optional[
            Callable[[np.ndarray, np.ndarray, np.ndarray], float]
        ] = None,
        calculate_safe_path_func: Optional[
            Callable[[np.ndarray, np.ndarray, List, float], List]
        ] = None,
    ):
        """
        Initialize mission state manager.

        Args:
            position_tolerance: Position error tolerance in meters
            angle_tolerance: Angle error tolerance in radians
            normalize_angle_func: Function to normalize angles to [-pi, pi]
            angle_difference_func: Function to calculate angle difference
            point_to_line_distance_func: Function to calculate point-to-line distance
            calculate_safe_path_func: Function to calculate safe path avoiding obstacles
        """
        self.position_tolerance = position_tolerance
        self.angle_tolerance = angle_tolerance

        # Store helper functions
        self.normalize_angle = normalize_angle_func or self._default_normalize_angle
        self.angle_difference = angle_difference_func or self._default_angle_difference
        self.point_to_line_distance = (
            point_to_line_distance_func or self._default_point_to_line_distance
        )
        self.calculate_safe_path = calculate_safe_path_func

        # Mission state tracking
        self.current_nav_waypoint_idx: int = 0
        self.nav_target_reached_time: Optional[float] = None

        self.dxf_completed: bool = False
        self.multi_point_target_reached_time: Optional[float] = None

        self.shape_stabilization_start_time: Optional[float] = None
        self.return_stabilization_start_time: Optional[float] = None
        self.final_waypoint_stabilization_start_time: Optional[float] = None

    @staticmethod
    def _default_normalize_angle(angle: float) -> float:
        """Default angle normalization to [-pi, pi]."""
        while angle > np.pi:
            angle -= 2 * np.pi
        while angle < -np.pi:
            angle += 2 * np.pi
        return angle
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

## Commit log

2025-11-18 Initial release v1.0.0
    Model Predictive Control for Satellite Navigation on Air-Bearing Testbed
    This is the initial public release of a complete MPC-based satellite control system
    developed for a Master's thesis at the University of Kentucky.
    Features:
    - Model Predictive Control with Gurobi optimization
    - Simulation and hardware control modes
    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
    [MPC_Thruster(1)_20250707_210016.csv, MPC_Thruster(1)_20250707_210431.csv, MPC_Thruster(2)_20250707_213517.csv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]
2025-11-18 Minor fixes and updates to simulation and real modules
    [real.py, simulation.py]
2025-11-18 Adding cad files
    [Seeed Studio XIAO-ESP32-S3-Sense_.step]
2025-11-18 Cad files added
    [1 to 3 Manifold.step, 1 to 8 Manifold.step, 1,,4 NPT Plug.step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]
2026-01-03 Remove GitHub issue templates, contributing guidelines, and .gitignore, add thesis documentation and Gurobi license, and update simulation timing, requirements, and MPC logic.
    [mpc.py]

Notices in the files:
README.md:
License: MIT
